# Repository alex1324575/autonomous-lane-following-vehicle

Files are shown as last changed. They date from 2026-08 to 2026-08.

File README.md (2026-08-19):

# Autonomous Lane-Following Vehicle

> UC Davis EEC 195A/B senior capstone (2024–2025) — a small autonomous vehicle that uses onboard vision and closed-loop steering to follow a marked lane.






## Overview

The vehicle converts a grayscale OpenMV camera image into a lane-center estimate, then uses a PID loop to command a steering servo. An IR sensor provides wheel-speed feedback; the cleaned firmware includes an optional speed-control loop and a conservative lane-loss failsafe.

**Competition outcome:** Team 16 completed two laps of the competition track in **49.3 seconds**, placing **7th overall**, as documented in the final project report.

The repository was reconstructed from the original capstone source and Altium project files in August 2026. It intentionally separates a deployable, documented firmware path from the historical experiment snapshots so the development process remains traceable.

## Prototype gallery

| Vehicle prototype | Lane-following test setup | Custom motor-control PCB |
| --- | --- | --- |
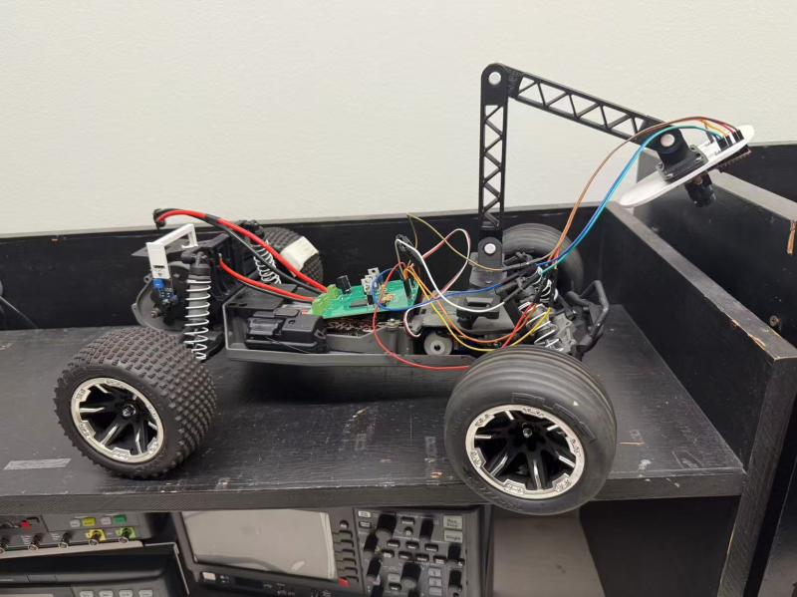
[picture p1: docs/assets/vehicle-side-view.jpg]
Side view of the assembled lane-following vehicle
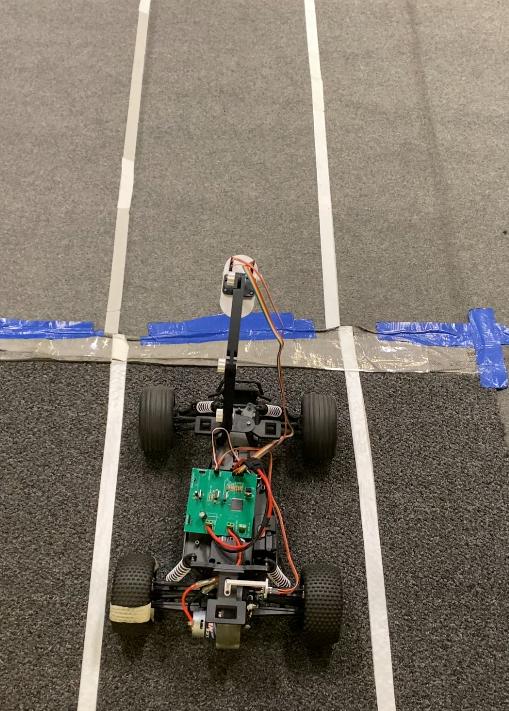
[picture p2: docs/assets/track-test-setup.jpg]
Vehicle positioned on the taped lane test track
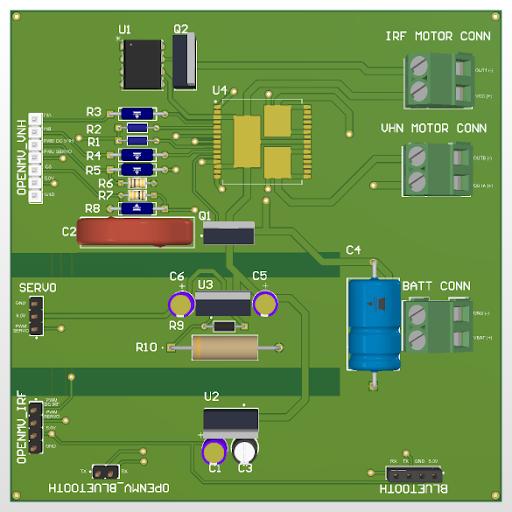
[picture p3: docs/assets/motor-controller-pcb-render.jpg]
Rendered custom motor-control PCB
|  |  |  |

The images show the assembled vehicle, the taped two-line track used for testing, and a rendered view of the custom motor-control board. They document the physical prototype; they do not by themselves establish a quantitative performance metric.

## Demonstration video

[Watch the original final time-trial run](docs/assets/final-time-trial-medium-slow.mov) (MOV, 97 MB).

This is the original submitted recording, retained as a primary demonstration artifact. For a public-facing portfolio, add a compressed MP4 or a hosted video link alongside it so visitors can preview the run without downloading the source file.

## System architecture

```mermaid
flowchart LR
    C[OpenMV Cam RT1062] -->|80 × 60 grayscale frame| V[Binary threshold + blob detection]
    V -->|left/right lane markers| E[Lane-center error]
    E --> P[Steering PID]
    P --> S[Servo PWM]
    I[IR wheel sensor] --> R[RPM estimator]
    R --> M[Optional speed PID]
    M --> D[DC motor PWM]
    S --> A[Steering servo]
    D --> H[Motor driver PCB]
    H --> W[Brushed DC motor]
```

## Repository layout

```text
firmware/openmv/       Cleaned OpenMV/MicroPython firmware to deploy
hardware/altium/       Native Altium project, schematic, and PCB layout
docs/                  Architecture, hardware, deployment, and validation notes
archive/firmware-history/
                        Unmodified historical iterations and experiments
```

## Hardware and software

| Area | Implementation |
| --- | --- |
| Vision | OpenMV Cam RT1062, grayscale QQQVGA (80 × 60), binary thresholding, blob-based lane center |
| Steering | PWM servo with configurable calibration limits and PID control |
| Drive | Brushed DC motor driven by the custom two-layer control PCB |
| Speed sensing | IR wheel/gear sensor with timer-window RPM estimation |
| Electronics | Altium Designer native schematic and PCB files |
| Mechanical | Adjustable 3D-printed camera mount (CAD source was not included in the recovered archive) |

See [architecture notes](docs/architecture.md) and [hardware notes](docs/hardware.md) for implementation details.

## Quick start

1. Install the OpenMV IDE and connect the OpenMV Cam RT1062.
2. Open [firmware/openmv/config.py](firmware/openmv/config.py) and calibrate the camera threshold, pin mapping, servo endpoints, and motor duty values for your vehicle.
3. Copy the four files in `firmware/openmv/` to the camera's filesystem, with `main.py` at the root.
4. Keep the wheels off the ground for the first run. Verify neutral steering, motor direction, and the lane-loss brake before track testing.

Detailed bring-up and safety guidance: [firmware/openmv/README.md](firmware/openmv/README.md).

## Design decisions

- **Blob-based lane center** was selected for the deployable firmware because the archive's final iteration detects left and right lane markers in a near-field region of interest, then steers to their midpoint.
- **Fixed camera settings** prevent auto-gain and white-balance changes from shifting the grayscale threshold during a run.
- **Speed control is documented, but deployment stays conservative.** The final report describes a second PID loop that adjusts motor PWM from IR-derived RPM. The recovered final code snapshot retains the measurement and PID pathway but leaves the output adjustment disabled. The reconstructed firmware exposes this loop behind `ENABLE_SPEED_PID` until it is recalibrated on the physical vehicle.
- **Safe lane-loss behavior** is the default: center steering immediately and brake after a small number of missed frames.

## Reported results and evidence

| Result | Reported value |
| --- | --- |
| Competition run | Two full laps |
| Completion time | 49.3 seconds |
| Overall rank | 7th |
| Field validation | 1,000+ real-world test runs |

These results and the design claims in this repository are sourced from the team-authored [final report](docs/reference/team-16-final-report.pdf) and [project poster](docs/reference/team-16-project-poster.pdf). The recovered archive still lacks raw telemetry, an exported BOM, Gerbers, and camera-mount CAD; the repository does not infer those missing artifacts.

Use the repeatable checklist in [docs/validation.md](docs/validation.md) for a new validation run.

## Historical source and attribution

`archive/firmware-history/` preserves the original files, including early line-regression and line-segment approaches. The cleaned firmware is a maintainable reconstruction based on the latest blob/PID implementation; it should be reviewed and calibrated before use on hardware. [Design rationale and source reconciliation](docs/design-decisions.md) explains the major choices and the differences between the report and recovered code snapshot.

This was a course team project. Confirm contributor names, institution branding, and reuse permissions with the team before publishing the repository under an open-source license.

## Roadmap

- [ ] Add schematic/PCB render exports and a BOM from Altium
- [ ] Add camera-mount CAD/STL files
- [ ] Add one full uncut track-run video and representative serial telemetry
- [ ] Tune and validate the optional speed PID on the final hardware
- [ ] Add a hardware-in-the-loop test record

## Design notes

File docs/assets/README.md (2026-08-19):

# Demo assets

| File | Description |
| --- | --- |
| `vehicle-side-view.jpg` | Assembled vehicle and elevated camera mount. |
| `track-test-setup.jpg` | Vehicle positioned on the taped lane-following test track. |
| `motor-controller-pcb-render.jpg` | Rendered custom motor-control PCB. |
| `final-time-trial-medium-slow.mov` | Original final time-trial recording (97 MB MOV). |

Future additions should include a thresholded-camera screenshot with lane markers. Before committing, remove course rosters, private contact details, room locations, and any media for which the team has not granted publication permission.

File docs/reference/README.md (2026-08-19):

# Project references

The files in this directory are team-authored historical artifacts retained as evidence for the repository documentation.

| File | Purpose |
| --- | --- |
| `team-16-final-report.pdf` | Final technical report: system design, hardware rationale, software flow, and competition outcome. |
| `team-16-project-poster.pdf` | Presentation poster: condensed architecture, hardware overview, and competition summary. |

These documents include team names, UC Davis branding, and cited third-party material. Confirm team permission and any course publication requirements before changing the repository to public.

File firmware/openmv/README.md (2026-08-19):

# OpenMV firmware

This directory contains the cleaned, deployable reconstruction of the final lane-center workflow from the capstone archive. It targets OpenMV MicroPython and is **not** intended to run under CPython.

## Files

- `main.py` — camera, GPIO/PWM initialization, control loop, and fail-safe behavior.
- `config.py` — every vehicle-specific calibration value in one place.
- `control.py` — lane detection, steering conversion, and RPM utilities.
- `pid.py` — small PID controller that uses MicroPython tick counters.

## Deploy

1. In OpenMV IDE, create or upload all four files to the board filesystem.
2. Run `main.py` from the board filesystem.
3. Set `DEBUG = True` during calibration and watch the serial terminal.
4. When the lane center is stable, disable `DEBUG` for less serial overhead.

## Required calibration

Do not use the default values as a hardware guarantee. Confirm each item on your vehicle:

1. **Camera threshold:** tune `LANE_THRESHOLD` under track lighting; the provided value assumes a light line on a darker track.
2. **Steering endpoints:** verify `STEERING_LEFT_NS`, `STEERING_CENTER_NS`, and `STEERING_RIGHT_NS` with wheels off the ground.
3. **Motor command:** begin at `MOTOR_BRAKE_NS`, then raise `MOTOR_BASE_NS` slowly. Verify the motor direction before placing the vehicle on a track.
4. **IR sensor:** confirm `IR_PIN`, `GEAR_MARKS`, and `RPM_WINDOW_MS` against the encoder disk/gear.
5. **Speed PID:** leave `ENABLE_SPEED_PID = False` until a new calibration log supports enabling it.

## Safety

The firmware centers steering when it cannot see both lane markers and brakes after `MAX_MISSED_LANE_FRAMES`. Test that behavior with the drive wheels lifted before every new wiring or parameter change.

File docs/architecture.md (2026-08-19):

# Control architecture

## Per-frame lane estimation

The OpenMV Cam RT1062 captures an 80 × 60 grayscale frame. Automatic gain and white balance are disabled after startup so that a fixed threshold can segment a light lane marker from a darker track. The controller searches a 30-pixel-high near-field region for connected white blobs:

1. The nearest candidate on the left of the frame center is the left marker.
2. The nearest candidate on the right is the right marker.
3. When both markers are available, their midpoint is the lane center.
4. A signed angular error is calculated from that point to the camera center.

The archived work shows earlier regression-line and `find_lines()` experiments. The final preserved `main.py` used the two-blob midpoint approach, which is why it is the basis of the cleaned firmware.

## Steering loop

The PID output is limited to ±45° and mapped linearly around the servo's calibrated neutral pulse. A small deadband avoids repeated micro-corrections near the centerline. Unlike the historical script, the cleaned controller resets the steering PID on lane loss and applies a staged response:

| Condition | Steering | Motor |
| --- | --- | --- |
| Both markers detected | PID command | Base duty or optional speed-PID duty |
| One missed frame | Center | Base duty |
| `MAX_MISSED_LANE_FRAMES` misses | Center | Brake |

## Speed measurement and optional speed loop

The IR sensor increments an edge counter in an interrupt. A periodic timer ends the measurement window; RPM is estimated from gear marks and the configured gear-to-wheel ratio. The final report describes a motor PID that clamps its PWM adjustment and adds it to the base motor command.

The latest recovered `main.py` retains the RPM path and motor PID object but leaves its PWM adjustment commented out. This repository preserves that distinction: `ENABLE_SPEED_PID` is `False` by default until the physical vehicle is recalibrated. The report is evidence of the final system design; the archived file is evidence of the particular recovered firmware snapshot.

## Interfaces beyond the control loop

The final report also documents an HC-06 Bluetooth header for wireless debugging and start/stop control, along with a current-sense feedback path from the H-bridge to the OpenMV. These interfaces are represented in the Altium design files but are not exercised by the recovered lane-following firmware.

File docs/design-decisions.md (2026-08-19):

# Design decisions and source reconciliation

This document connects the recovered source files to the team-authored final report and poster. It helps distinguish verified project history from configuration that must be revalidated on a future build.

## Vision strategy

The archive preserves multiple approaches: regression-line detection, Hough-style line detection, and the final left/right blob midpoint approach. The documented final flow uses grayscale QQQVGA frames, a binary threshold, a near-field bottom ROI, and `find_blobs()` to identify both lane markers. The maintainable firmware in `firmware/openmv/` follows that final approach.

## Dual PID design

The report describes independent steering and motor-speed PID controllers. Steering maps a bounded lane error to servo PWM. Motor control estimates RPM from a HiLetgo IR sensor and slotted gear, then clamps the PWM adjustment before applying it to the motor command.

The code snapshot preserved in `archive/firmware-history/main.py` measures RPM and creates a motor PID object, but its final motor-PWM adjustment remains disabled. This may reflect a test configuration rather than the final competition configuration. To avoid claiming a fresh validation, the cleaned firmware keeps speed PID opt-in until tested on the physical system.

## PCB architecture

The report explains why the PCB carries redundant brushed-motor control paths: a VNH5019ATR-E H-bridge supports bidirectional drive and current sense, while the IRF3205/MAX4427 path provides low-side PWM control. It also records separate logic, servo, and motor ground pours meeting at a battery-side star point. The native Altium project remains the authoritative engineering source.

## Camera-mount iteration

The first camera stand was rigid but fixed-angle, making field-of-view tuning expensive. The team then built an adjustable stand to change pitch and height during track testing. Initial video jitter was traced to loose chassis fasteners rather than the printed structure; replacing them with M3 machine screws eliminated the issue. The final mount was printed in PETG and used reinforced joints and truss cutouts to balance rigidity and weight.

## Evidence hierarchy

1. The physical vehicle, current calibration, and a new test log are the authority for a renewed run.
2. The native Altium project is the authority for the PCB design.
3. The final report and poster are the authority for historical results and design narrative.
4. `archive/firmware-history/` is an unmodified record of recovered implementation iterations.
5. `firmware/openmv/` is a cleaned reconstruction for review and future calibration.

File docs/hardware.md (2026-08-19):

# Hardware design

The recovered Altium sources are tracked under [`hardware/altium/`](../hardware/altium/):

- `Lab_8_v3.PrjPcb` — Altium project
- `Lab_8_v3.SchDoc` — schematic source
- `Lab_8_v3.PcbDoc` — PCB layout source

Rendered custom motor-control PCB

Open the `.PrjPcb` file in Altium Designer to regenerate manufacturing outputs and documentation. The archive did not include a BOM, Gerbers, pick-and-place output, 3D model, or rendered schematic. Do not infer those artifacts from this repository; regenerate and review them from the native project before fabrication.

## Documented design details

The final report provides the following implementation record for the recovered PCB:

| Area | Documented implementation |
| --- | --- |
| Motor drive | Two isolated paths: VNH5019ATR-E H-bridge with current sense, and IRF3205PBF low-side MOSFET driven by MAX4427CPA+ |
| Current feedback | H-bridge CS output filtered by a 10 kOhm / 33 nF RC network and routed to OpenMV |
| Logic power | LM2940CT-5.0 5 V rail for OpenMV and HC-06, with 0.47 uF and 22 uF support capacitors |
| Servo power | LM1086CT-ADJ configured for a 6 V rail, with R9 = 470 Ohm, R10 = 121 Ohm, and 10 uF capacitors |
| Ground strategy | GNDA, GND_SERVO, and GND_LOGIC pours joined at one star point near the battery connector |
| Layout and fabrication | Two layers, board size below 100 mm x 100 mm, 10 A high-current trace sizing, DRC reported as passed before Gerber export |

The report identifies JLCPCB as the fabrication service. It also records that the VNH5019 was assembled by pick-and-place and the remaining components were hand-soldered. Treat these details as a design record, not as current fabrication instructions: regenerate all manufacturing outputs from the native Altium project and complete an electrical review before building another board.

## Recovered interface map

The pin mapping below is taken from the latest archived firmware and is consolidated in `firmware/openmv/config.py`.

| Function | OpenMV pin | Notes |
| --- | --- | --- |
| Servo PWM | P2 | 100 Hz, calibrated around 1.5 ms |
| Motor PWM | P8 | 1.6 kHz |
| Motor direction A | P10 | Driven high in the final forward-only configuration |
| Motor direction B | P9 | Driven low in the final forward-only configuration |
| IR speed input | P5 | Falling-edge interrupt with pull-up |
| IR sensor ground | P6 | Driven low |

## Publication checklist

Before publishing fabrication-ready hardware, export and review:

1. PDF schematic and high-resolution PCB renders.
2. BOM with manufacturer part numbers and quantity.
3. Gerber, drill, board-outline, and pick-and-place files.
4. Power-tree and motor-current calculations.
5. Revision, date, and electrical-rule-check status.

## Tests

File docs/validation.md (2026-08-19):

# Validation checklist

## Historical outcome

The team final report records two completed competition laps in 49.3 seconds and a 7th-place overall result. It also reports more than 1,000 real-world test runs. These are historical project outcomes, not results regenerated by this repository.

This checklist provides a protocol for a future repeatable validation run.

## Bench bring-up

- [ ] Confirm the board powers the camera, servo, motor driver, and IR sensor at their expected voltages.
- [ ] Verify the camera image and threshold before connecting the drive motor.
- [ ] With the wheels raised, check servo neutral and both steering limits.
- [ ] Verify forward motor direction and brake command.
- [ ] Confirm one timer window of IR edges produces a plausible RPM estimate.
- [ ] Cover one lane marker and verify that the failsafe centers then brakes.

## Track test record

For every run, log the following in a CSV or notebook and retain a synchronized video if possible:

| Field | Example |
| --- | --- |
| Firmware commit | `git rev-parse --short HEAD` |
| Track / lighting | indoor, LED overhead, matte black track |
| Threshold | `(215, 255)` |
| Base motor duty | `85000 ns` |
| Steering gains | `Kp=3.0, Ki=0.0, Kd=0.6` |
| Speed feedback | disabled / enabled |
| Outcome | completed / lane loss / mechanical issue |
| Notes | turns, lighting transitions, observed oscillation |

## Acceptance criteria for a renewed demonstration

Define the track and metrics before running. A useful minimum is: complete a specified track for three consecutive runs without manual intervention, retain one uncut video, and record the exact firmware commit and calibration used.

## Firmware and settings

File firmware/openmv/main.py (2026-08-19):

"""OpenMV entry point for the autonomous lane-following vehicle.

Deploy this file with config.py, control.py, and pid.py to the OpenMV board.
Always calibrate with the vehicle lifted and confirm the lane-loss brake.
"""

import sensor
import time
from machine import LED, PWM, Pin, Timer

import config
from control import clamp, find_lane_center, rpm_from_edges, steering_error_degrees, steering_pulse_ns
from pid import PID


edge_count = 0
rpm_window_ready = False


def on_ir_edge(_pin):
    global edge_count
    if not rpm_window_ready:
        edge_count += 1


def on_rpm_window(_timer):
    global rpm_window_ready
    rpm_window_ready = True


def set_status(leds, color=None):
    for led in leds:
        led.off()
    if color == "red":
        leds[0].on()
    elif color == "green":
        leds[1].on()
    elif color == "blue":
        leds[2].on()


def initialize_camera():
    sensor.reset()
    sensor.set_pixformat(sensor.GRAYSCALE)
    sensor.set_framesize(sensor.QQQVGA)
    sensor.skip_frames(time=2_000)
    sensor.set_auto_gain(False)
    sensor.set_auto_whitebal(False)


def main():
    global edge_count, rpm_window_ready

    initialize_camera()

    motor_ina = Pin(config.MOTOR_INA_PIN, Pin.OUT)
    motor_inb = Pin(config.MOTOR_INB_PIN, Pin.OUT)
    motor_ina.value(1)
    motor_inb.value(0)

    servo = PWM(config.SERVO_PIN, freq=config.SERVO_FREQUENCY_HZ,
                duty_u16=32768)
    motor = PWM(config.MOTOR_PWM_PIN, freq=config.MOTOR_FREQUENCY_HZ,
                duty_u16=32768)
    servo.duty_ns(config.STEERING_CENTER_NS)
    motor.duty_ns(config.MOTOR_BRAKE_NS)

    ir_sensor = Pin(config.IR_PIN, Pin.IN, Pin.PULL_UP)
    ir_ground = Pin(config.IR_GROUND_PIN, Pin.OUT)
    ir_ground.value(0)
    ir_sensor.irq(handler=on_ir_edge, trigger=Pin.IRQ_FALLING)
    Timer(-1, mode=Timer.PERIODIC, period=config.RPM_WINDOW_MS,
          callback=on_rpm_window)

    leds = [LED("LED_RED"), LED("LED_GREEN"), LED("LED_BLUE")]
    steering_pid = PID(config.STEERING_KP, config.STEERING_KI,
                       config.STEERING_KD, config.STEERING_INTEGRAL_LIMIT)
    speed_pid = PID(config.SPEED_KP, config.SPEED_KI,
                    config.SPEED_KD, config.SPEED_INTEGRAL_LIMIT)
    clock = time.clock()
    missed_lane_frames = 0
    current_rpm = 0.0

    # Hold the vehicle stationary long enough for a safe initial check.
    time.sleep(2)

    while True:
        if rpm_window_ready:
            current_rpm = rpm_from_edges(edge_count)
            edge_count = 0
            rpm_window_ready = False

        clock.tick()
        image = sensor.snapshot().binary([config.LANE_THRESHOLD])
        lane_center, left_marker, right_marker = find_lane_center(image)

        if lane_center is None:
            missed_lane_frames += 1
            steering_pid.reset()
            servo_pulse = config.STEERING_CENTER_NS
            motor_pulse = (config.MOTOR_BRAKE_NS
                           if missed_lane_frames >= config.MAX_MISSED_LANE_FRAMES
                           else config.MOTOR_BASE_NS)
            set_status(leds)
            error = 0.0
            steering_command = 0.0
        else:
            missed_lane_frames = 0
            error = steering_error_degrees(lane_center)
            steering_command = steering_pid.update(error)
            servo_pulse = steering_pulse_ns(steering_command)

            motor_pulse = config.MOTOR_BASE_NS
            if config.ENABLE_SPEED_PID:
                speed_adjustment = speed_pid.update(config.TARGET_RPM - current_rpm)
                motor_pulse = clamp(config.MOTOR_BASE_NS + speed_adjustment,
                                    config.MOTOR_MIN_NS, config.MOTOR_MAX_NS)

            if steering_command > config.STEERING_DEADBAND_DEGREES:
                set_status(leds, "blue")
            elif steering_command < -config.STEERING_DEADBAND_DEGREES:
                set_status(leds, "red")
            else:
                set_status(leds, "green")

        servo.duty_ns(int(servo_pulse))
        motor.duty_ns(int(motor_pulse))

        if config.DEBUG:
            print("lane={}, left={}, right={}, err={:.2f}, steer={:.2f}, rpm={:.1f}, "
                  "servo={}, motor={}, fps={:.1f}".format(
                      lane_center, left_marker, right_marker, error,
                      steering_command, current_rpm, int(servo_pulse),
                      int(motor_pulse), clock.fps()))


main()

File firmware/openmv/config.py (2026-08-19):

"""Vehicle-specific configuration for the OpenMV lane-following firmware.

All pulse widths are in nanoseconds. Values are recovered from the final
capstone iteration and must be verified against the actual vehicle before use.
"""

# Camera and image processing
FRAME_WIDTH = 80                 # OpenMV QQQVGA
FRAME_HEIGHT = 60
LANE_THRESHOLD = (215, 255)      # Light line on a darker track
ROI_HEIGHT = 30                  # Near-field region used for lane markers
BLOB_PIXELS_THRESHOLD = 7
BLOB_AREA_THRESHOLD = 7

# OpenMV pin mapping recovered from the final source revision
SERVO_PIN = "P2"
MOTOR_PWM_PIN = "P8"
MOTOR_INA_PIN = "P10"
MOTOR_INB_PIN = "P9"
IR_PIN = "P5"
IR_GROUND_PIN = "P6"

# PWM and actuator calibration
SERVO_FREQUENCY_HZ = 100
MOTOR_FREQUENCY_HZ = 1600
STEERING_LEFT_NS = 1_100_000
STEERING_CENTER_NS = 1_500_000
STEERING_RIGHT_NS = 1_900_000
MAX_STEERING_DEGREES = 45
STEERING_DEADBAND_DEGREES = 5

MOTOR_BRAKE_NS = 0
MOTOR_BASE_NS = 85_000
MOTOR_MIN_NS = 55_000
MOTOR_MAX_NS = 100_000

# Steering PID gains from the final archived main.py revision
STEERING_KP = 3.0
STEERING_KI = 0.0
STEERING_KD = 0.6
STEERING_INTEGRAL_LIMIT = 25.0

# Wheel-speed sensing and optional speed feedback
GEAR_MARKS = 3
GEAR_TO_WHEEL_RATIO = 1.0
RPM_WINDOW_MS = 250
TARGET_RPM = 40.0
ENABLE_SPEED_PID = False          # Enable only after recalibration
SPEED_KP = 1.0
SPEED_KI = 0.0
SPEED_KD = 0.0
SPEED_INTEGRAL_LIMIT = 5_000.0

# Safety and diagnostics
MAX_MISSED_LANE_FRAMES = 3
DEBUG = True

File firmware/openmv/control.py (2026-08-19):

"""Vision and actuator helpers that are independent of board initialization."""

from math import atan2, pi

import config


def find_lane_center(image):
    """Return the midpoint of the nearest detected left/right lane markers.

    The camera image is expected to be binary, with white lane pixels. The
    search deliberately uses a near-field ROI, matching the final archived
    blob-detection implementation.
    """
    roi = (0, config.FRAME_HEIGHT - config.ROI_HEIGHT,
           config.FRAME_WIDTH, config.ROI_HEIGHT)
    blobs = image.find_blobs(
        [(255, 255)],
        roi=roi,
        pixels_threshold=config.BLOB_PIXELS_THRESHOLD,
        area_threshold=config.BLOB_AREA_THRESHOLD,
        merge=True,
    )

    frame_center_x = config.FRAME_WIDTH // 2
    left_marker = None
    right_marker = None

    for blob in blobs:
        x, y = blob.cx(), blob.cy()
        if x < frame_center_x:
            if left_marker is None or x > left_marker[0]:
                left_marker = (x, y)
        elif right_marker is None or x < right_marker[0]:
            right_marker = (x, y)

        if config.DEBUG:
            image.draw_rectangle(blob.rect(), color=127)
            image.draw_cross(x, y, color=127)

    if left_marker is None or right_marker is None:
        return None, left_marker, right_marker

    center = ((left_marker[0] + right_marker[0]) // 2,
              (left_marker[1] + right_marker[1]) // 2)
    return center, left_marker, right_marker


def steering_error_degrees(lane_center):
    """Convert lane-center displacement to a bounded angular error."""
    x_distance = (config.FRAME_WIDTH / 2) - lane_center[0]
    y_distance = max(1, config.FRAME_HEIGHT - lane_center[1])
    error = atan2(x_distance, y_distance) * (180 / pi)
    return clamp(error, -config.MAX_STEERING_DEGREES,
                 config.MAX_STEERING_DEGREES)


def steering_pulse_ns(turning_degrees):
    """Map a signed steering command to a calibrated servo pulse width."""
    turning_degrees = clamp(turning_degrees, -config.MAX_STEERING_DEGREES,
                            config.MAX_STEERING_DEGREES)
    if abs(turning_degrees) < config.STEERING_DEADBAND_DEGREES:
        turning_degrees = 0

    if turning_degrees >= 0:
        span = config.STEERING_RIGHT_NS - config.STEERING_CENTER_NS
    else:
        span = config.STEERING_CENTER_NS - config.STEERING_LEFT_NS

    return int(config.STEERING_CENTER_NS +
               (turning_degrees / config.MAX_STEERING_DEGREES) * span)


def rpm_from_edges(edge_count):
    """Estimate wheel RPM from IR edges accumulated over one configured window."""
    gear_rpm = (edge_count / config.GEAR_MARKS) * (60_000 / config.RPM_WINDOW_MS)
    return gear_rpm / config.GEAR_TO_WHEEL_RATIO


def clamp(value, lower, upper):
    return max(lower, min(upper, value))

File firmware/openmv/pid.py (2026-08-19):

"""Small MicroPython-friendly PID controller with integral anti-windup."""

import time


class PID:
    def __init__(self, kp, ki, kd, integral_limit):
        self.kp = float(kp)
        self.ki = float(ki)
        self.kd = float(kd)
        self.integral_limit = float(integral_limit)
        self.reset()

    def reset(self):
        self._previous_error = None
        self._previous_time_us = None
        self._integral = 0.0

    def update(self, error):
        now_us = time.ticks_us()
        if self._previous_time_us is None:
            self._previous_time_us = now_us
            self._previous_error = error
            return 0.0

        dt = time.ticks_diff(now_us, self._previous_time_us) / 1_000_000
        if dt <= 0:
            return 0.0

        self._integral += 0.5 * (error + self._previous_error) * dt
        self._integral = max(-self.integral_limit,
                             min(self.integral_limit, self._integral))
        derivative = (error - self._previous_error) / dt

        self._previous_error = error
        self._previous_time_us = now_us
        return (self.kp * error) + (self.ki * self._integral) + (self.kd * derivative)
